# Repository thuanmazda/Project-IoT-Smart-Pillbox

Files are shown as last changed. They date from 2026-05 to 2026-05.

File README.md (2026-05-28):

# 💊 IoT Smart Pillbox - Hộp Thuốc Thông Minh





**IoT Smart Pillbox** là hệ thống hộp thuốc điện tử thông minh được thiết kế nhằm hỗ trợ người cao tuổi và bệnh nhân trong việc tuân thủ phác đồ điều trị. Dự án ứng dụng vi điều khiển ESP32, kết hợp đồng bộ hóa đám mây qua Google Apps Script và hệ thống cảnh báo tức thời qua Telegram.

> **Đồ án môn học 1 (EE3183)** > Khoa Điện - Điện tử, Trường Đại học Bách Khoa - ĐHQG TP.HCM.

---

## ✨ Tính năng nổi bật
* **Định thời gian thực chuẩn xác:** Sử dụng module RTC DS3231 đảm bảo báo thức hoạt động chính xác ngay cả khi mất kết nối Internet.
* **Cấu hình Wi-Fi động (Captive Portal):** Cho phép người dùng kết nối mạng mới thông qua điện thoại thông minh (WiFiManager) mà không cần nạp lại mã nguồn.
* **Theo dõi & Báo cáo đám mây:** Tự động đẩy lịch sử đóng/mở nắp hộp (thông qua công tắc hành trình) lên Google Sheets.
* **Cảnh báo Telegram tức thời:** Gửi tin nhắn thông báo cho người nhà khi đến giờ uống thuốc, uống thuốc trễ hoặc mở hộp sai giờ.
* **Tối ưu năng lượng:** Tích hợp tính năng Deep Dimming (giảm sáng màn hình OLED) để tiết kiệm pin tối đa.
* **Lưu trữ ngoại tuyến (Offline Mode):** Lưu trữ tạm thời dữ liệu vào bộ nhớ Flash (NVS) khi rớt mạng và tự động đồng bộ lại khi có kết nối.

---

## 📂 Cấu trúc thư mục (Directory Tree)

```text
IoT-Smart-Pillbox/
├── 📁 Firmware/
│   └── 📄 ESP32_Pillbox.ino          # Mã nguồn C++ nạp cho vi điều khiển ESP32 (File đọc Arduino IDE)
│   └── 📄 ESP32_Pillbox.cpp          # Mã nguồn C++ nạp cho vi điều khiển ESP32 (File chuẩn hoá định dạng code C++)
├── 📁 Web_App_Script/
│   ├── 📄 Code.gs                    # Mã nguồn Backend (Google Apps Script)
│   └── 📄 Index.html                 # Giao diện Web quản lý (Frontend)
├── 📁 Hardware/
│   ├── 📄 Schematic_Altium.pdf       # File PDF bản vẽ sơ đồ nguyên lý
│   └── 📄 BOM.xlsx                   # Bảng danh mục vật tư (Bill of Materials)
│   └── 📁 Altium PCB Project         # Thư mục chứa toàn bộ dự án thiết kế PCB bằng Altium
├── 📁 Docs/
│   ├── 📄 BAO_CAO_DO_AN_1.pdf        # File báo cáo chi tiết của đề tài
│   └── 📁 Source_Code_LaTeX          # Source Code LaTeX của bài báo cáo 
└── 📄 README.md                      # Tài liệu hướng dẫn của đề tài

```
## 🛠️ Cài đặt & Triển khai hệ thống

### 1. Thi công phần cứng
* Lắp ráp các linh kiện điện tử theo đúng sơ đồ nguyên lý (`Schematic_Altium.pdf`) được cung cấp trong thư mục `Hardware`.
* Dưới đây là hình ảnh nguyên mẫu phần cứng sau khi thi công và tích hợp vào vỏ hộp:

> **📸 Hình ảnh mạch thực tế:**
> 
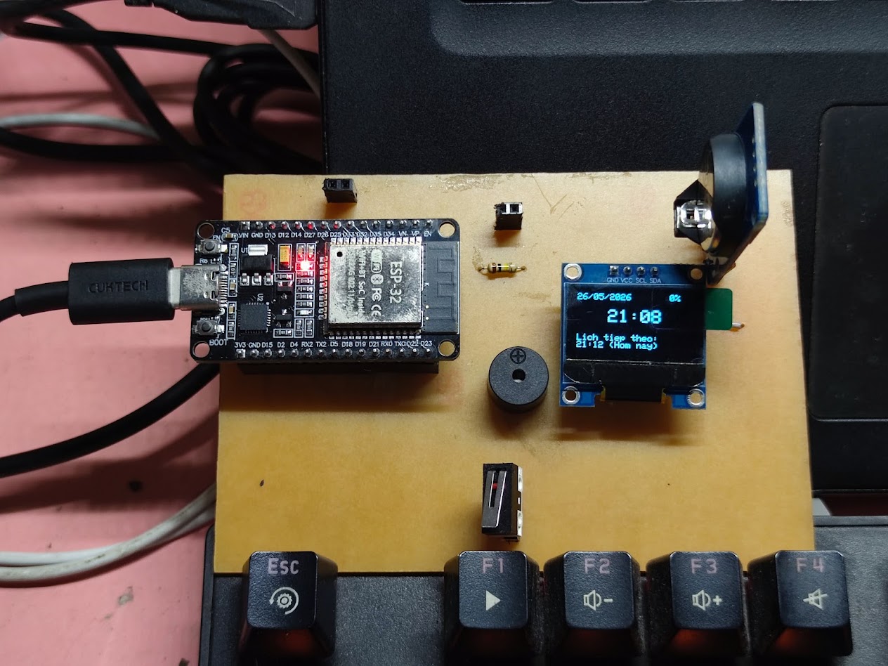
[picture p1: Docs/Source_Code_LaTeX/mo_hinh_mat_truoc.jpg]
Mô hình hoàn thiện
> 

---

### 2. Triển khai Cơ sở dữ liệu (Google Sheets & Apps Script)
Hệ thống sử dụng Google Sheets làm cơ sở dữ liệu miễn phí và Google Apps Script làm Backend API.

1. **Tạo Google Sheet:** Tạo một bảng tính mới để lưu trữ nhật ký.
   * 👉 [🔗 Cơ sở dữ liệu Google Sheet của dự án](https://docs.google.com/spreadsheets/d/1F7vB3ncXRynr4YONkt-7NzRndev7CFtMYesXiH4w0Is/edit?usp=sharingx)
2. **Triển khai Script:** * Mở `Tiện ích mở rộng` -> `Apps Script`.
   * Copy nội dung file `Web_App_Script/Code.gs` và `Index.html` dán vào.
   * Chọn `Phát triển` -> `Triển khai mới` -> Chọn loại `Ứng dụng Web` (Quyền truy cập: Bất kỳ ai).
   * **Lưu lại đường dẫn Web App URL** để nạp vào ESP32.
   * 👉 [🔗 Đường link Web Dashboard của dự án](https://script.google.com/macros/s/AKfycbyWvpzWuLJ_vV84Uc3rvG5cOGRKCblE85hYOkTFurOL_UT4WP3MSYsnFkm6WfHzJIYH/exec)

---

### 3. Nạp mã nguồn ESP32 (Firmware)
1. Cài đặt [Arduino IDE](https://www.arduino.cc/en/software) và thêm board ESP32 vào Board Manager.
2. Cài đặt các thư viện bắt buộc thông qua Library Manager:
   * `WiFiManager` (bởi tzapu)
   * `RTClib` (bởi Adafruit)
   * `Adafruit SSD1306` & `Adafruit GFX Library`
   * `NTPClient` (bởi Fabrice Weinberg)
3. Mở file `Firmware/ESP32_Pillbox.ino`.
4. Tìm đến vùng cấu hình và thay thế các thông số sau bằng thông tin của bạn:
   ```cpp
   String googleScriptUrl = "Dán_Web_App_URL_của_bạn_vào_đây";
   String botToken = "Dán_Token_Telegram_Bot_của_bạn_vào_đây";
   String chatId = "Dán_Chat_ID_của_bạn_vào_đây";
   ```
5. Kết nối ESP32 với máy tính qua cáp Type-C và bấm Upload.

## 🚀 Hướng dẫn Sử dụng Hệ thống

Bước 1: Cấu hình mạng Wi-Fi (Captive Portal)
   * Cấp nguồn cho thiết bị. Nếu mạch chưa có thông tin Wi-Fi, nó sẽ tự động phát ra một mạng Wi-Fi có tên là `Hop_thuoc_IoT`.
   * Dùng điện thoại kết nối vào mạng Wi-Fi này. Một trang đăng nhập sẽ tự động hiện ra (Captive Portal). Bạn chỉ cần chọn mạng Wi-Fi nhà mình, nhập mật khẩu và bấm Save. Thiết bị sẽ tự khởi động lại và online.

Bước 2: Cài đặt lịch trình qua Web Dashboard
  * Truy cập vào đường dẫn Web App (từ bước triển khai Apps Script) bằng điện thoại hoặc máy tính.
  * Tại đây, người quản lý có thể cập nhật các cữ thuốc, xem lịch sử đóng/mở nắp và kiểm tra thống kê tuân thủ.

> **📸 Giao diện Trang quản trị Web:**
> 
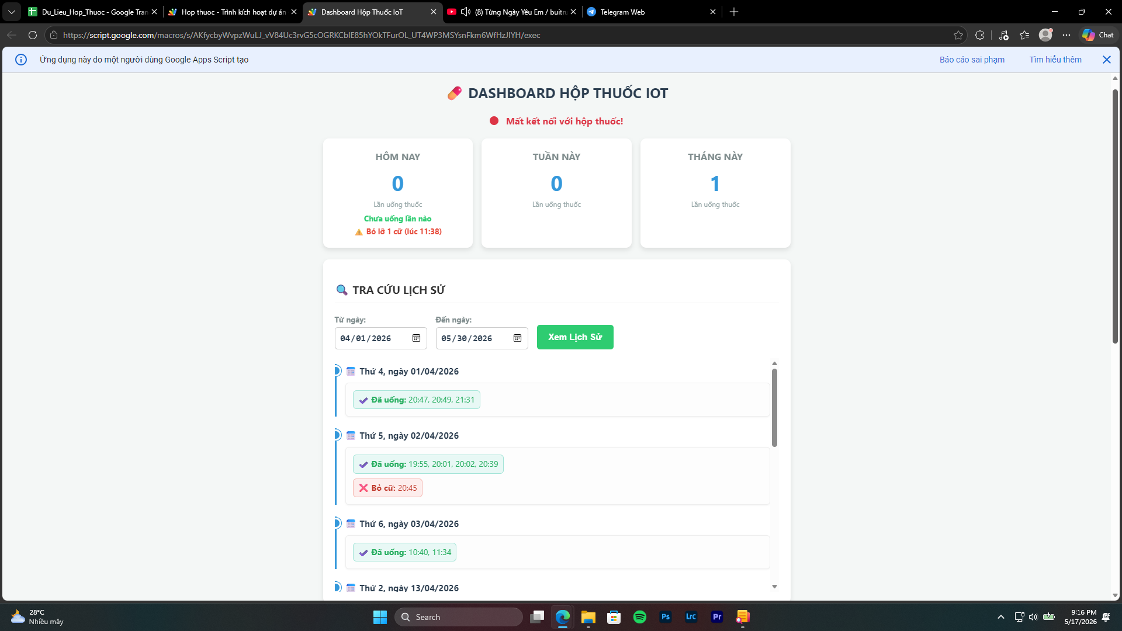
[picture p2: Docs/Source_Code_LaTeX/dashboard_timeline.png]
Giao diện trang web
> 

Bước 3: Nhận thông báo qua Telegram
  * Khi đến giờ, hộp thuốc sẽ phát tiếng bíp và sáng màn hình.
  * Khi người bệnh mở nắp đúng giờ hoặc sai giờ, tin nhắn cảnh báo sẽ ngay lập tức được đẩy về ứng dụng Telegram của người nhà.

> **📸 Thông báo Telegram Bot:**
> 
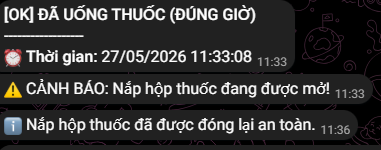
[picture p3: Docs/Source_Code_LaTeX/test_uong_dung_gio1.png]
Thông báo Telegram
> 

---

## 📄 Bản quyền và Cấp phép (Credits & License)

Dự án này là sản phẩm thuộc **Đồ án môn học 1 (EE3183)**. 
Bản quyền mã nguồn, tài liệu và thiết kế cơ khí thuộc về chủ sở hữu (**Nguyễn Minh Thuận**) và **Khoa Điện - Điện tử, Trường Đại học Bách Khoa - ĐHQG TP.HCM**. 

*Vui lòng trích dẫn nguồn đầy đủ và tôn trọng quyền tác giả nếu bạn tham khảo hoặc sử dụng lại các tài liệu từ kho lưu trữ này cho mục đích học tập.*

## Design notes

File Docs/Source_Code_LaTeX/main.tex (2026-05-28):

\documentclass[12pt, a4paper, oneside]{article}
\usepackage[utf8]{vietnam}
\usepackage[utf8]{inputenc}
\usepackage[left=40mm, right=25mm, top=40mm, bottom=25mm]{geometry}
\usepackage{amsmath,amsfonts,amssymb}
\usepackage{indentfirst,enumitem}
\usepackage{graphicx}
\usepackage{multicol}
\usepackage{multirow}
\usepackage{setspace}
\usepackage{hyperref}
\usepackage{listings}
\usepackage{tabularx}
\usepackage{hyperref}
\usepackage{xcolor}
\usepackage{scrextend}
\usepackage{comment}
\usepackage{soul}
\usepackage{tipa}
\usepackage{subcaption}
\usepackage{caption}
\usepackage{booktabs}
\usepackage{array}
\usepackage{fancyhdr}
\usepackage{algorithm2e}
\usepackage{float}
\usepackage[most]{tcolorbox}
\usepackage{pdfpages}
\usepackage{import}
\usepackage{fancyhdr}
\usepackage[T5]{fontenc} % Hỗ trợ tiếng Việt
\usepackage{mathptmx} % Gói Times Roman
\graphicspath{ {figures/} }
\usepackage{titlesec}
\usepackage{tikz}
\usetikzlibrary{shapes.geometric, arrows, positioning, calc}
% Cấu hình Tiêu đề Chương (Section): Canh giữa, in hoa, đậm, cỡ 14
\titleformat{\section}[block]
  {\centering\normalfont\fontsize{14pt}{16.8pt}\bfseries\MakeUppercase}
  {\thesection}
  {0.5em}
  {}
% Cấu hình Tiêu đề Mục (Subsection): Đậm, chữ thường
\titleformat{\subsection}[hang]
  {\normalfont\normalsize\bfseries}
  {\thesubsection}
  {0.5em}
  {}

\captionsetup[table]{position=top, labelfont=bf, textfont=it, font=small, skip=5pt}
\captionsetup[figure]{position=bottom, labelfont=bf, textfont=it, font=small, skip=5pt}

\hypersetup{
    colorlinks=true,
    linkcolor=black,
    filecolor=magenta,      
    urlcolor=black,
    pdftitle={TKHTN},
    pdfpagemode=FullScreen,
}

\changefontsizes{13pt}
\renewcommand\thesection{\arabic{section}.}
\renewcommand\thesubsection{\arabic{section}.\arabic{subsection}}
\setlength{\parindent}{1.25cm}

\pagestyle{fancy}
\renewcommand{\headrulewidth}{0pt}
\fancyhf{} % Xóa cấu hình mặc định
\cfoot{\thepage} % Số trang ở giữa dưới (thường dùng)

\def\mathrlap{\mathpalette\mathrlapinternal} 
\def\mathclap{\mathpalette\mathclapinternal}
\def\mathllapinternal#1#2{\llap{$\mathsurround=0pt#1{#2}$}}
\def\mathrlapinternal#1#2{\rlap{$\mathsurround=0pt#1{#2}$}}

%CHÈN ẢNH
\usepackage{pgfplots}
\pgfplotsset{compat=1.15}
\usepackage{mathrsfs}
\usetikzlibrary{arrows}
\usetikzlibrary[patterns]

%New colors defined below
\definecolor{codegreen}{rgb}{0,0.6,0}
\definecolor{codegray}{rgb}{0.5,0.5,0.5}
\definecolor{codepurple}{rgb}{0.58,0,0.82}
\definecolor{backcolour}{rgb}{0.95,0.95,0.92}

%Code listing style named "mystyle"
\lstdefinestyle{mystyle}{
  backgroundcolor=\color{backcolour},   commentstyle=\color{codegreen},
  keywordstyle=\color{blue},
  numberstyle=\tiny\color{codegray},
  stringstyle=\color{codepurple},
  basicstyle=\ttfamily\footnotesize,
  breakatwhitespace=false,         
  breaklines=true,                 
  captionpos=b,                    
  keepspaces=true,                 
  numbers=left,                    
  numbersep=5pt,                  
  showspaces=false,                
  showstringspaces=false,
  showtabs=false,                  
  tabsize=2
}

%"mystyle" code listing set
\lstset{style=mystyle}

\begin{document}
\begin{titlepage}
%\SetWatermarkText{\includegraphics[width = 0.97\paperwidth,
%height = 0.97\paperheight]{bia.png}}
%\SetWatermarkAngle{0} 
%\SetWatermarkText{\includegraphics[scale=1]{hust.png}}
%\SetWatermarkAngle{0} 
\begin{tikzpicture}[remember picture,overlay,inner sep=0,outer sep=0]
     % Đã đổi xshift ở B và C từ 1.5cm thành 3cm để dịch khung sang phải né gáy sách 40mm
     \draw[blue!70!black,line width=4pt] ([xshift=-1.5cm,yshift=-2cm]current page.north east) coordinate (A)--([xshift=3cm,yshift=-2cm]current page.north west) coordinate(B)--([xshift=3cm,yshift=2cm]current page.south west) coordinate (C)--([xshift=-1.5cm,yshift=2cm]current page.south east) coordinate(D)--cycle;

     \draw ([yshift=0.5cm,xshift=-0.5cm]A)-- ([yshift=0.5cm,xshift=0.5cm]B)--
     ([yshift=-0.5cm,xshift=0.5cm]B) --([yshift=-0.5cm,xshift=-0.5cm]B)--([yshift=0.5cm,xshift=-0.5cm]C)--([yshift=0.5cm,xshift=0.5cm]C)--([yshift=-0.5cm,xshift=0.5cm]C)-- ([yshift=-0.5cm,xshift=-0.5cm]D)--([yshift=0.5cm,xshift=-0.5cm]D)--([yshift=0.5cm,xshift=0.5cm]D)--([yshift=-0.5cm,xshift=0.5cm]A)--([yshift=-0.5cm,xshift=-0.5cm]A)--([yshift=0.5cm,xshift=-0.5cm]A);

     \draw ([yshift=-0.3cm,xshift=0.3cm]A)-- ([yshift=-0.3cm,xshift=-0.3cm]B)--
     ([yshift=0.3cm,xshift=-0.3cm]B) --([yshift=0.3cm,xshift=0.3cm]B)--([yshift=-0.3cm,xshift=0.3cm]C)--([yshift=-0.3cm,xshift=-0.3cm]C)--([yshift=0.3cm,xshift=-0.3cm]C)-- ([yshift=0.3cm,xshift=0.3cm]D)--([yshift=-0.3cm,xshift=0.3cm]D)--([yshift=-0.3cm,xshift=-0.3cm]D)--([yshift=0.3cm,xshift=-0.3cm]A)--([yshift=0.3cm,xshift=0.3cm]A)--([yshift=-0.3cm,xshift=0.3cm]A);
\end{tikzpicture}
\begin{center}
    \vspace{7pt}
        \textbf{ĐẠI HỌC QUỐC GIA THÀNH PHỐ HỒ CHÍ MINH}
    
    \vspace{7pt}
    {TRƯỜNG ĐẠI HỌC BÁCH KHOA}
    
    \vspace{7pt}
    {KHOA ĐIỆN - ĐIỆN TỬ}

\end{center}
\vspace{10pt}
\begin{center}
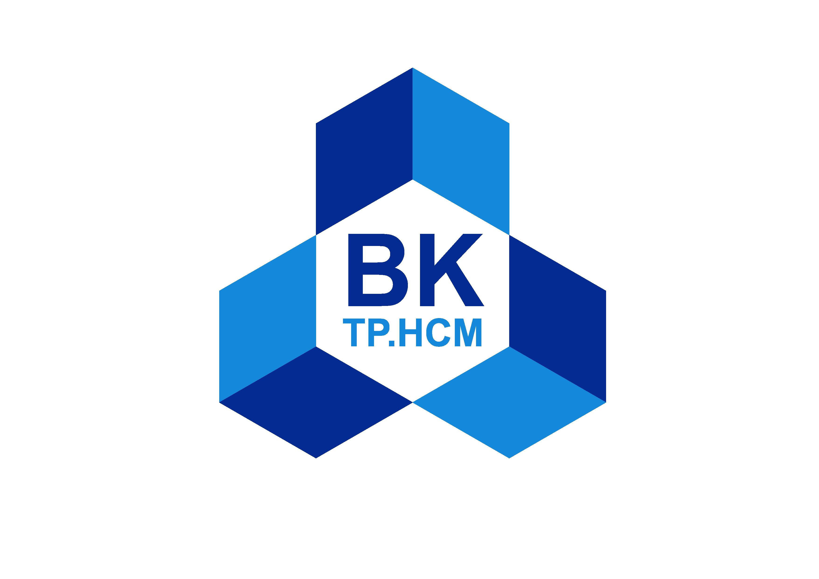
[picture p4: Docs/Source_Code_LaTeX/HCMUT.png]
    
    
    \vspace{10pt}
\end{center}

\begin{center}
    \fontsize{18pt}{17pt}\selectfont 
    \textbf{ĐỒ ÁN MÔN HỌC 1 (EE3183)}
\end{center}
\begin{center}
    \fontsize{15pt}{17pt}\selectfont 
    \textbf{\textrm{ĐỀ TÀI: THIẾT KẾ HỘP THUỐC THÔNG MINH IOT - 
    \\
    IOT SMART PILLBOX}}
\end{center}

\begin{center}
    \vspace{15pt}
% \textbf{Lớp: L03 - NHÓM: 5}
\end{center}

\vspace{10pt}

\begin{table}[h]
\begin{tabular}{rrl}
\hspace{6 cm} & SVTH: &Nguyễn Minh Thuận\\
& MSSV: &2313355\\
& GVHD: &TS. Nguyễn Thanh Tuấn
\end{tabular}
\end{table}
\vfill
\centerline{\bf Thành phố Hồ Chí Minh, tháng 6 năm 2026}

\vspace{1cm}
\end{titlepage}

\newpage

\newpage
\thispagestyle{empty}
\setstretch{1.3}
\begin{center}
    \textbf{LỜI CẢM ƠN}
\end{center}

\textit{Em xin gửi lời cảm ơn chân thành và sự tri ân sâu sắc đối với thầy Nguyễn Thanh Tuấn, giảng viên Bộ môn Viễn Thông, Khoa Điện - Điện tử, Trường Đại học Bách khoa - Đại học Quốc gia Thành phố Hồ Chí Minh, đã tạo điều kiện cho em có thể hoàn thành được học phần Đồ Án 1 này. Và em cũng xin chân thành cảm ơn thầy đã nhiệt tình hướng dẫn, chỉ ra những điều còn thiếu sót trong qua trình thực hiện đề tài để có được kết quả tốt đẹp như mong muốn và hoàn thành tốt học phần này.}

\textit{Trong quá trình thực hiện đề tài, thầy đã chỉ dẫn, góp ý và giúp em khắc phục những thiếu sót để đạt được kết quả tốt hơn. Do hạn chế về kiến thức và kinh nghiệm thực tiễn, bài báo cáo không thể tránh khỏi những sai sót. Em rất mong nhận được sự thông cảm và những ý kiến đóng góp quý báu từ thầy để có thể hoàn thiện hơn trong các học phần tiếp theo cũng như trong đồ án và luận văn tốt nghiệp sau này.}

\textit{Em xin chân thành cảm ơn Thầy!}

\textit{Chúc Thầy sức khỏe và thành đạt.}

\vspace{4cm}

\hspace{5cm}\textit{Tp. Hồ Chí Minh, ngày .... tháng .... năm ........}

\hspace{8cm}\textbf{Sinh viên}

\newpage
\thispagestyle{empty}
\setstretch{1.3}
\begin{center}
    \textbf{TÓM TẮT ĐỀ TÀI}
\end{center}

Tuân thủ phác đồ điều trị và uống thuốc đúng giờ là yếu tố tiên quyết quyết định hiệu quả của quá trình chăm sóc y tế, đặc biệt đối với người cao tuổi và bệnh nhân mắc các bệnh mãn tính. Tuy nhiên, tình trạng quên uống thuốc, uống sai cữ hoặc bỏ liều vẫn thường xuyên diễn ra do sự suy giảm trí nhớ hoặc nhịp sống bận rộn. Nhằm giải quyết triệt để vấn đề này, đề tài "Thiết kế hộp thuốc thông minh IoT - IoT Smart Pillbox" được triển khai với mục tiêu xây dựng một hệ sinh thái hỗ trợ quản lý y tế cá nhân khép kín, tự động và theo thời gian thực. 

Cốt lõi của hệ thống được phát triển dựa trên vi điều khiển trung tâm ESP32, kết hợp cùng công tắc hành trình để giám sát chính xác các thao tác vật lý, màn hình OLED 0.96 inch để giao tiếp trực quan và còi báo chủ động nhằm tạo ra chu trình nhắc nhở hiệu quả. Thiết bị đảm bảo tính di động và vận hành liên tục nhờ cơ chế cấp nguồn linh hoạt qua cổng USB Type-C hoặc hệ thống pin Lithium-ion đi kèm mạch quản lý năng lượng. 

Điểm đột phá của đề tài nằm ở việc ứng dụng kiến trúc điện toán phi máy chủ (Serverless) thay cho các máy chủ trung gian truyền thống, sử dụng Google Apps Script làm nền tảng Backend và Google Sheets làm cơ sở dữ liệu. Nhờ triển khai các thuật toán xử lý đa nhiệm không đồng bộ (non-blocking) trên vi điều khiển, thiết bị có khả năng đánh giá và phân loại chính xác các trạng thái phức tạp như "Đã uống", "Bỏ thuốc" hay "Uống trễ". Toàn bộ dữ liệu được đồng bộ hóa với một trang quản trị trực tuyến (Web Dashboard), cho phép người nhà hoặc bác sĩ dễ dàng thiết lập lịch trình từ xa, tra cứu nhật ký y tế và nhận thông báo cảnh báo tức thời qua ứng dụng Telegram. 

Kết quả thực nghiệm khẳng định hệ thống vận hành ổn định, độ trễ truyền tải thấp và logic xử lý đáp ứng trọn vẹn các kịch bản thực tế, qua đó mở ra tiềm năng ứng dụng mạnh mẽ cho các thiết bị y tế thông minh phân tán trong tương lai.

\newpage
\thispagestyle{empty}
\setstretch{1.3}
\renewcommand{\contentsname}{\centering {MỤC LỤC}}
\tableofcontents

\newpage
\setcounter{page}{1}

\begin{center}
    \section{GIỚI THIỆU}
\end{center}
\subsection{Tổng quan}
%Nội dung 1.1
Sự phát triển bùng nổ của Internet vạn vật (IoT) đã và đang tạo ra những bước nhảy vọt trong lĩnh vực y tế số (Digital Health). Xu hướng chuyển dịch từ việc chăm sóc sức khỏe tập trung tại bệnh viện sang giám sát cá nhân hóa tại gia đình đang ngày càng trở nên phổ biến. Trong bối cảnh đó, vấn đề tuân thủ thời gian biểu sử dụng thuốc (Medication Adherence) nổi lên như một thách thức lớn. Theo nhiều báo cáo y khoa, việc người bệnh (đặc biệt là người cao tuổi, người suy giảm trí nhớ) quên uống thuốc, uống quá liều hoặc sai cữ không chỉ làm vô hiệu hóa phác đồ điều trị mà còn gây ra những biến chứng nguy hiểm, gia tăng gánh nặng cho hệ thống y tế.

Xuất phát từ nhu cầu thực tiễn cấp thiết đó, đề tài "Thiết kế hộp thuốc thông minh IoT" được đề xuất và thực hiện. Không chỉ dừng lại ở một thiết bị phần cứng phát tiếng kêu báo thức đơn thuần, đề tài hướng tới việc xây dựng một hệ thống quản lý dữ liệu y tế toàn diện. Sự kết hợp giữa vi điều khiển có kết nối Wi-Fi (ESP32) tại nơi người bệnh và sức mạnh xử lý của điện toán đám mây (Cloud Computing) tạo ra một luồng thông tin xuyên suốt. Người nhà hoặc bác sĩ có thể dễ dàng thiết lập phác đồ uống thuốc từ xa, trong khi hệ thống phần cứng sẽ tự động tương tác với bệnh nhân và gửi báo cáo hành vi chi tiết (đúng giờ, trễ giờ, bỏ cữ) theo thời gian thực về máy chủ.

\subsection{Tình hình nghiên cứu trong và ngoài nước}
%Nội dung 1.2
\subsubsection{Tình hình nghiên cứu ngoài nước:} 

Trên thị trường quốc tế, các sản phẩm hộp thuốc thông minh đã bắt đầu được thương mại hóa, tiêu biểu như các dòng sản phẩm của Ellie, Medisafe hay Hero. Các hệ thống này thường có thiết kế cơ khí tinh xảo, phân chia nhiều ngăn tự động. Về mặt công nghệ, chúng chủ yếu sử dụng giao thức Bluetooth (BLE) để đồng bộ dữ liệu với ứng dụng trên điện thoại thông minh (Smartphone) của người dùng, hoặc sử dụng Wi-Fi để kết nối với các máy chủ đám mây độc quyền (Proprietary Cloud). Nhược điểm chung của các giải pháp này là giá thành phần cứng rất cao, bắt buộc người dùng phải trả phí thuê bao (Subscription) hàng tháng để duy trì dịch vụ lưu trữ dữ liệu, và quá trình thiết lập ứng dụng đi kèm khá phức tạp đối với tệp người dùng là người cao tuổi.

\subsubsection{Tình hình nghiên cứu trong nước:} 

Tại Việt Nam, các nghiên cứu và sản phẩm ứng dụng IoT trong quản lý hộp thuốc chủ yếu xuất hiện dưới dạng các mô hình đồ án sinh viên hoặc sản phẩm khởi nghiệp quy mô nhỏ. Đa số các mô hình sử dụng vi điều khiển như Arduino Uno kết hợp module ESP8266, hoặc sử dụng cơ sở dữ liệu thời gian thực Firebase của Google. Dù giải quyết được bài toán chi phí, nhưng các mô hình này thường thiếu tính đồng bộ và độ tin cậy. Các hệ thống đa phần gặp giới hạn ở việc xử lý đa nhiệm (bị treo hệ thống khi chờ kết nối mạng), không có giao diện Web tổng quan (Dashboard) độc lập mà phụ thuộc vào các nền tảng có sẵn như Blynk, và chưa tối ưu hóa được thuật toán phân tích hành vi "uống trễ" của người bệnh.

Đề tài này được thực hiện nhằm khắc phục các nhược điểm trên, bằng cách tự chủ hoàn toàn giao diện Web, tận dụng kiến trúc API của Google Apps Script để miễn phí hóa khâu lưu trữ, và xây dựng một nền tảng phần mềm nhúng hoạt động ổn định không bị tắc nghẽn.

\subsection{Nhiệm vụ đề tài}
%Nội dung 1.3
Để đạt được các mục tiêu đã đề ra, đề tài tập trung giải quyết các nhiệm vụ trọng tâm sau:
\begin{itemize}
    \item \textbf{Thiết kế và thi công phần cứng:} Lựa chọn linh kiện và thiết kế sơ đồ mạch điện xung quanh vi điều khiển trung tâm ESP32. Tích hợp màn hình OLED I2C, còi báo động, công tắc hành trình dạng đòn bẩy nảy (Limit switch).
    \item \textbf{Phát triển phần mềm nhúng:} Lập trình ESP32 trên nền tảng C++ với thuật toán xử lý đa nhiệm theo thời gian thực sử dụng hàm \texttt{millis()}, loại bỏ hoàn toàn các hàm dừng (delay) gây treo hệ thống. Triển khai giao thức NTP để đồng bộ thời gian chuẩn xác và HTTPS để truyền/nhận dữ liệu bảo mật.
    \item \textbf{Thiết kế hệ thống Điện toán đám mây:} Xây dựng mã nguồn Google Apps Script (GAS) đóng vai trò làm máy chủ API, xử lý các yêu cầu GET/POST từ mạch ESP32 và định tuyến dữ liệu vào bảng tính Google Sheets để lưu trữ dài hạn.
    \item \textbf{Phát triển Giao diện Người dùng (UI/UX):} Thiết kế và lập trình một trang Web Dashboard (sử dụng HTML/CSS/JavaScript) cho phép thiết lập lịch báo thức đa dạng (theo thứ trong tuần) và hiển thị thống kê lịch sử trực quan. Tích hợp API của Telegram để khởi tạo Bot thông báo từ xa.
    \item \textbf{Thử nghiệm và đánh giá:} Cấu hình cơ chế khôi phục mạng nội bộ và tiến hành đánh giá độ ổn định của toàn bộ hệ thống dưới các điều kiện vận hành thực tế.
\end{itemize}

\newpage
\begin{center}
    \section{LÝ THUYẾT}
\end{center}
%Nội dung chương 2
\subsection{Vi điều khiển trung tâm ESP32 NodeMCU Devkit V1}
\subsubsection{Kiến trúc phần cứng vi xử lý}

ESP32 NodeMCU Devkit V1 là bo mạch phát triển mã nguồn mở, được thiết kế tích hợp module hệ thống trên chip (SoC) ESP32-WROOM-32 do hãng Espressif Systems sản xuất.

Trái tim của hệ thống là bộ vi xử lý Xtensa® Dual-Core 32-bit LX6. Khác với các dòng vi điều khiển lõi đơn truyền thống như ATmega328P, kiến trúc lõi kép của ESP32 mang lại khả năng xử lý bất đối xứng trên nền tảng hệ điều hành thời gian thực FreeRTOS.

\begin{itemize}
    \item \textit{ Lõi PRO\_CPU}: Chuyên trách xử lý các luồng tác vụ ngầm ở tầng thấp như ngăn xếp giao thức Wi-Fi, Bluetooth và quản lý các ngắt phần cứng cường độ cao.
    \item \textit{Lõi APP\_CPU}: Được giải phóng hoàn toàn để thực thi mã chương trình của người dùng (logic giám sát hành trình nắp hộp, xuất tín hiệu âm thanh và cập nhật màn hình OLED). 
    Hệ thống sử dụng đường dẫn dữ liệu (Data bus) và đường dẫn lệnh (Instruction bus) độc lập theo kiến trúc Harvard, mang lại khả năng tính toán lên đến 600 DMIPS, đáp ứng hoàn hảo yêu cầu phân tích (parsing) các chuỗi dữ liệu JSON phức tạp tải về từ máy chủ đám mây.
\end{itemize}

\begin{figure}
    \centering
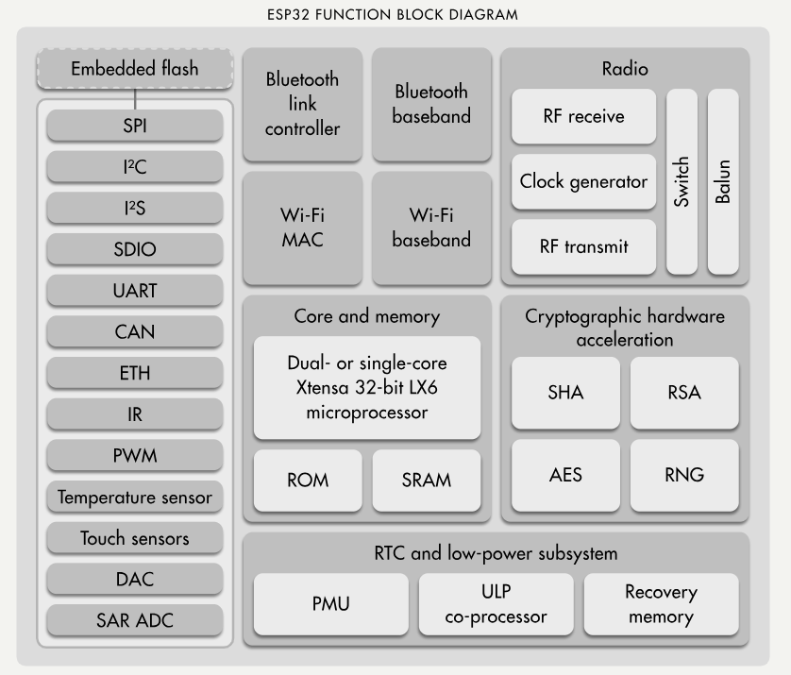
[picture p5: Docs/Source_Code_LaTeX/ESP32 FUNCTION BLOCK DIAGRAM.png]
    
    \caption{Sơ đồ khối chức năng của ESP32}
    \label{fig:espblockdiagram}
\end{figure}

\newpage
\subsubsection{Thông số kỹ thuật chi tiết và Ngoại vi}

Dựa trên tài liệu kỹ thuật của nhà sản xuất, SoC ESP32-WROOM-32 sở hữu các thông số phần cứng vượt trội, đáp ứng tiêu chuẩn của một thiết bị IoT công nghiệp:

\begin{itemize}
    \item Hệ thống Nguồn điện: Điện áp hoạt động lõi của chip là $2.2V - 3.6V$. Tuy nhiên, trên mạch Devkit V1 đã được tích hợp sẵn IC ổn áp tuyến tính như AMS1117-3.3, cho phép cấp nguồn $5V$ an toàn qua cổng Micro-USB hoặc chân VIN. Chip được trang bị bộ xử lý đồng xử lý siêu tiết kiệm năng lượng (ULP), cho phép dòng tiêu thụ giảm xuống mức cực thấp (khoảng $10 \mu A$) ở chế độ Ngủ sâu (Deep-sleep), rất lý tưởng cho các thiết bị y tế chạy pin.
    \item Hệ thống Bộ nhớ: Tích hợp sẵn $520 KB$ SRAM nội bộ và $448 KB$ ROM. Ngoài ra, module WROOM-32 được gắn kèm một chip nhớ Flash SPI ngoại vi dung lượng $4MB$ (hoặc $8MB$ tùy phiên bản), cung cấp không gian rộng rãi để lưu trữ Firmware, hệ thống tệp tĩnh (SPIFFS) và cơ sở dữ liệu nội bộ.
    \item Giao tiếp Ngoại vi (I/O Interfaces): Mạch cung cấp tổng cộng 34 chân GPIO với khả năng ghép kênh linh hoạt bằng phần mềm.
    \begin{itemize}
        \item Giao tiếp số: Hỗ trợ phần cứng chuyên dụng cho 3 x UART, 3 x SPI, 2 x I2C và 2 x I2S
        \item Giao tiếp tương tự: Tích hợp bộ chuyển đổi tương tự - số (ADC) kiến trúc SAR 12-bit với 18 kênh; và bộ chuyển đổi số - tương tự (DAC) 8-bit với 2 kênh.
        \item Cảm biến tích hợp: Chip tích hợp sẵn cảm biến hiệu ứng Hall (đo từ trường) và 10 chân GPIO hỗ trợ cảm biến điện dung, cho phép thiết kế các nút bấm không tiếp xúc cơ học.
    \end{itemize}
\end{itemize}
\subsubsection{Khả năng vô tuyến: Wi-Fi và Bluetooth}
Khả năng tích hợp RF trên ESP32 là một bước tiến lớn trong thiết kế bán dẫn, bao gồm bộ thu phát vô tuyến, bộ khuếch đại nhiễu thấp (LNA), bộ khuếch đại công suất (PA) và bộ chuyển mạch ăng-ten (Antenna switch) được nhúng gọn trong cùng một đế silicon (kích thước chỉ $18mm \times 25.5mm$).

\begin{itemize}
    \item Tầng Vật lý Wi-Fi: Tuân thủ chuẩn IEEE 802.11 b/g/n, hoạt động ở băng tần $2.4 GHz$ ISM. ESP32 hỗ trợ cấu trúc liên kết mạng linh hoạt: chế độ Station (thiết bị đầu cuối kết nối vào Router), SoftAP (tự phát mạng nội bộ) và kết hợp BSS. Với công suất phát định mức lên đến $+19.5 dBm$ (chuẩn 802.11b) và độ nhạy thu (RX Sensitivity) đạt $-97 dBm$, thiết bị đảm bảo duy trì liên kết vô tuyến ổn định, khắc phục hiện tượng suy hao tín hiệu khi hộp thuốc đặt trong phòng kín hoặc vùng có vật cản.
    \item Kết nối Bluetooth: Tích hợp bộ điều khiển băng tần cơ sở hỗ trợ chuẩn Bluetooth v4.2 BR/EDR và đặc biệt là Bluetooth Low Energy (BLE). Trong kiến trúc IoT hiện đại, BLE mở ra hướng phát triển cho việc cấu hình mạng cục bộ hoặc giao tiếp trực tiếp với các thiết bị đeo tay thông minh của người bệnh để đồng bộ nhịp tim và nhắc nhở uống thuốc mà không cần thông qua Internet.
\end{itemize}
\subsection{Nền tảng Giao thức Mạng và Đồng bộ hệ thống}

Để hiện thực hóa kiến trúc Internet vạn vật (IoT), hệ thống không giới hạn ở tầng vật lý mà đòi hỏi việc thực thi các ngăn xếp giao thức (Protocol Stack) chuẩn mực trên nền tảng TCP/IP, đảm bảo tính bảo mật và độ chính xác thời gian tuyệt đối.

\subsubsection{Giao thức HTTPS (Hypertext Transfer Protocol Secure)}

Trong đề tài này, ESP32 tương tác trực tiếp với hệ sinh thái máy chủ đám mây của Google (Google Apps Script) mà không qua bất kỳ Broker trung gian nào. Do tính chất dữ liệu y tế cần độ bảo mật cao, giao thức HTTPS được áp dụng tại tầng Ứng dụng (Application Layer).

HTTPS là phần mở rộng bảo mật của giao thức HTTP, hoạt động qua cổng 443. Khác với giao thức HTTP truyền văn bản gốc (plaintext) dễ bị tấn công nghe lén (Packet Sniffing), HTTPS thiết lập một đường hầm bảo mật bằng giao thức TLS/SSL (Transport Layer Security).

\begin{itemize}
    \item Quá trình Handshake: ESP32 và máy chủ Google trao đổi thông tin để thống nhất bộ thuật toán mã hóa (Cipher Suite).
    \item Mã hóa phi đối xứng: Sử dụng các thuật toán như RSA hay ECC để trao đổi khóa phiên một cách an toàn.
    \item Mã hóa đối xứng: Sau khi có khóa phiên, toàn bộ dữ liệu tải trọng (Payload) – bao gồm lệnh Mo\_Nap hay chuỗi lịch sử báo thức – đều được mã hóa bằng AES-256.
    
    Đặc tính kỹ thuật trên ESP32: Quá trình xác thực chứng chỉ số tốn rất nhiều tài nguyên RAM. Để tối ưu hóa giới hạn bộ nhớ của vi điều khiển, thư viện \texttt{WiFiClientSecure} được cấu hình ở chế độ \texttt{setInsecure()}. Kỹ thuật này bỏ qua việc kiểm tra tính hợp lệ của chuỗi chứng chỉ máy chủ nhưng vẫn duy trì kênh mã hóa dữ liệu đầu cuối, đảm bảo cân bằng giữa bài toán bảo mật và hiệu năng phần cứng nhúng.
\end{itemize}

\subsubsection{Giao thức đồng bộ thời gian mạng NTP (Network Time Protocol)}

Tính năng cốt lõi của "Hộp thuốc thông minh" là báo thức chính xác. Do ESP32 không được trang bị mạch đồng hồ thời gian thực (RTC) chạy pin CMOS độc lập, việc lấy giờ chuẩn được phó thác hoàn toàn cho giao thức NTP.

NTP hoạt động trên nền tảng giao thức phi kết nối UDP (User Datagram Protocol) tại cổng 123. Nó được thiết kế để đồng bộ hóa đồng hồ của các hệ thống máy tính với các nguồn thời gian chuẩn toàn cầu (Stratum 1, Stratum 2).

Thuật toán cốt lõi của NTP không chỉ đơn thuần là "hỏi giờ". Khi ESP32 gửi gói tin yêu cầu đến máy chủ (ví dụ \texttt{pool.ntp.org}), thuật toán sẽ ghi nhận 4 dấu thời gian (timestamps): thời điểm đi, thời điểm máy chủ nhận, thời điểm máy chủ phản hồi và thời điểm ESP32 nhận lại. Dựa vào 4 biến số này, ngăn xếp giao thức sẽ tính toán được:

\begin{itemize}
    \item Độ trễ đường truyền (Network Delay): Tổng thời gian gói tin di chuyển trên không gian mạng.
    \item Độ lệch đồng hồ (Clock Offset): Sự chênh lệch thời gian thực tế giữa hệ thống dao động thạch anh nội bộ của ESP32 và đồng hồ nguyên tử của máy chủ.
    
Bằng cách bù trừ các sai số này, giao thức NTP cung cấp cho hộp thuốc một mốc thời gian (Epoch time) với sai số chỉ ở mức mili-giây, đảm bảo cữ thuốc được nhắc nhở chính xác theo thời gian thực tại múi giờ địa phương (GMT+7).
\end{itemize}

\subsection{Màn hình OLED 0.96 inch và Giao thức I2C}

\begin{figure}[H]
    \centering
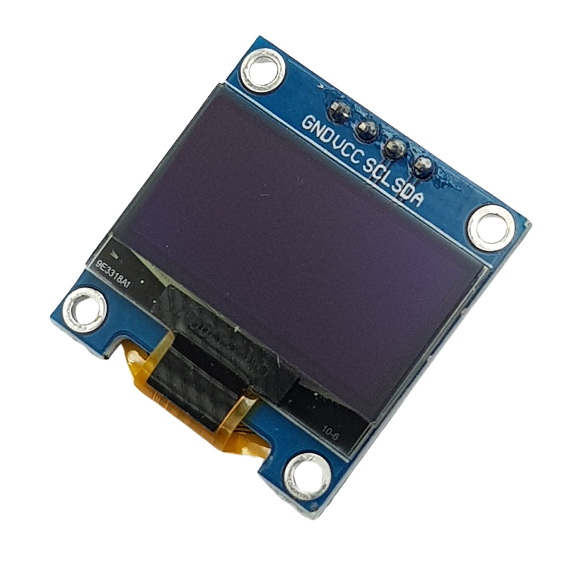
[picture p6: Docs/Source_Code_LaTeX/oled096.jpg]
    
    \caption{Màn hình OLED 0.96 Inch 128x64}
    \label{fig:oled096}
\end{figure}

\subsubsection{Nguyên lý công nghệ hiển thị OLED}

OLED (Organic Light Emitting Diode) là công nghệ đi-ốt phát quang hữu cơ. Khác với màn hình LCD (Liquid Crystal Display) truyền thống sử dụng một tấm đèn nền (Backlight) chiếu sáng liên tục xuyên qua các tinh thể lỏng, màn hình OLED hoạt động dựa trên hiện tượng phát quang điện từ (Electroluminescence) của vật liệu hữu cơ. Khi có một điện áp được đặt giữa cực Anode và Cathode, các lỗ trống và electron sẽ di chuyển và tái hợp tại lớp phát sáng hữu cơ, giải phóng năng lượng dưới dạng photon ánh sáng.

Nhờ khả năng "tự phát sáng" tại từng điểm ảnh (pixel), màn hình OLED có thể tắt hoàn toàn các pixel tại vùng hiển thị màu đen. Điều này tạo ra độ tương phản gần như vô hạn, không có hiện tượng hở sáng (light bleeding) và mức tiêu thụ năng lượng cực thấp (chỉ khoảng 20mA - 30mA khi hiển thị văn bản).

\subsubsection{Giao thức I2C (Inter-Integrated Circuit)}

Để điều khiển 8192 điểm ảnh (128x64 pixel), module sử dụng IC điều khiển SSD1306 tích hợp bộ nhớ GDDRAM (Graphic Display Data RAM) tĩnh dung lượng 1KB. Thay vì sử dụng chuẩn SPI song song tốn nhiều chân GPIO, module OLED này giao tiếp với ESP32 thông qua bus I2C đa chủ - đa tớ (Multi-master, Multi-slave).

I2C hoạt động thông qua hai đường tín hiệu truyền dẫn đồng bộ:

\begin{itemize}
    \item SDA (Serial Data Line): Đường truyền dữ liệu hai chiều dạng nối tiếp.
    \item SCL (Serial Clock Line): Đường xung nhịp đồng bộ, được tạo ra bởi thiết bị Chủ (ESP32).
\end{itemize}

Quá trình giao tiếp bắt đầu khi ESP32 kéo đường SDA xuống mức Thấp (LOW) trong khi SCL đang ở mức Cao (HIGH), tạo ra điều kiện Khởi động (Start Condition). Tiếp theo, ESP32 gửi đi byte Địa chỉ thiết bị (Device Address - của màn hình OLED thường là 0x3C). SSD1306 nhận dạng địa chỉ và trả về một bit xác nhận (ACK). Sau đó, ESP32 tiến hành truyền các luồng dữ liệu (Data frames) chứa mã lệnh cấu hình (Command) hoặc mã ma trận điểm ảnh (Data) vào vùng nhớ GDDRAM, quá trình kết thúc bằng điều kiện Dừng (Stop Condition). Tốc độ truyền tải I2C trong cấu hình mặc định đạt 100 kHz (Standard-mode) hoặc 400 kHz (Fast-mode), hoàn toàn đáp ứng được tốc độ làm tươi màn hình thời gian thực của đồ án.

\subsection{Còi báo hiệu chủ động (Active Buzzer) và Hiệu ứng Áp điện}

\newpage
\begin{figure}
    \centering
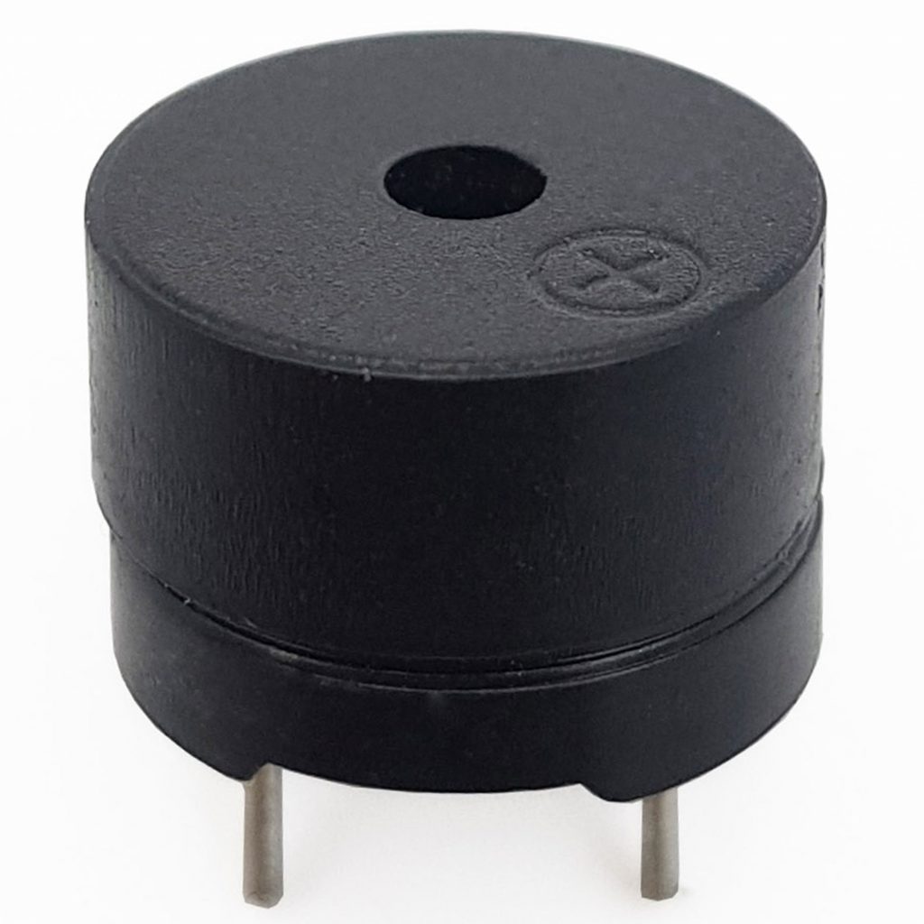
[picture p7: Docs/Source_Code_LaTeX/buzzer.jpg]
    
    \caption{Buzzer Chirp}
    \label{fig:buzzer}
\end{figure}

\newpage
\subsubsection{Cấu trúc và Hiệu ứng Áp điện nghịch}

Buzzer trong đề tài sử dụng bộ chuyển đổi âm thanh dạng áp điện (Piezoelectric transducer). Thành phần cốt lõi của nó là một đĩa gốm áp điện (thường làm từ vật liệu Lead Zirconate Titanate - PZT) được dán chặt vào một tấm màng kim loại mỏng (màng rung).

Nguyên lý hoạt động dựa trên Hiệu ứng áp điện nghịch (Inverse Piezoelectric Effect): Khi đặt một điện trường (bằng cách cấp điện áp) xuyên qua màng gốm PZT, mạng tinh thể của vật liệu sẽ bị biến dạng cơ học (co lại hoặc giãn ra). Khi đặt một dòng điện xoay chiều (AC) vào đĩa gốm, sự biến dạng liên tục và có chu kỳ sẽ khiến tấm màng kim loại uốn cong qua lại, từ đó đẩy lớp không khí xung quanh, tạo ra sóng âm thanh truyền đến tai người.

\subsubsection{Kiến trúc Mạch dao động nội (Active Circuitry)}

Khác biệt hoàn toàn với Passive Buzzer (cần vi điều khiển cấp xung PWM xoay chiều để tạo âm thanh), Active Buzzer được coi là một "linh kiện thông minh" độc lập vì nó tích hợp sẵn một mạch dao động đa hài (Multivibrator Oscillator circuit) ngay trên bo mạch nền của vỏ còi.

Mạch dao động này thường bao gồm các transistor và tụ điện, thiết lập sẵn một dải tần số cộng hưởng cố định (ví dụ: 2500 Hz). Khi vi điều khiển ESP32 xuất một tín hiệu logic mức CAO (3.3V) từ chân GPIO vào chân điều khiển của Buzzer, tín hiệu điện một chiều (DC) này sẽ cung cấp năng lượng cho mạch đa hài. Mạch đa hài tự động băm dòng điện DC thành các xung vuông AC ở tần số 2500 Hz và cấp thẳng vào đĩa áp điện. Nhờ đặc tính này, hệ thống nhúng giảm tải được hoàn toàn việc phải sử dụng các bộ định thời (Timer) phức tạp để tạo xung âm thanh, thay vào đó chỉ cần điều khiển trạng thái BẬT/TẮT ở tầng ứng dụng.

\subsection{Công tắc hành trình (Micro Limit Switch) và Cơ chế Cơ điện}

\begin{figure}[H]
    \centering
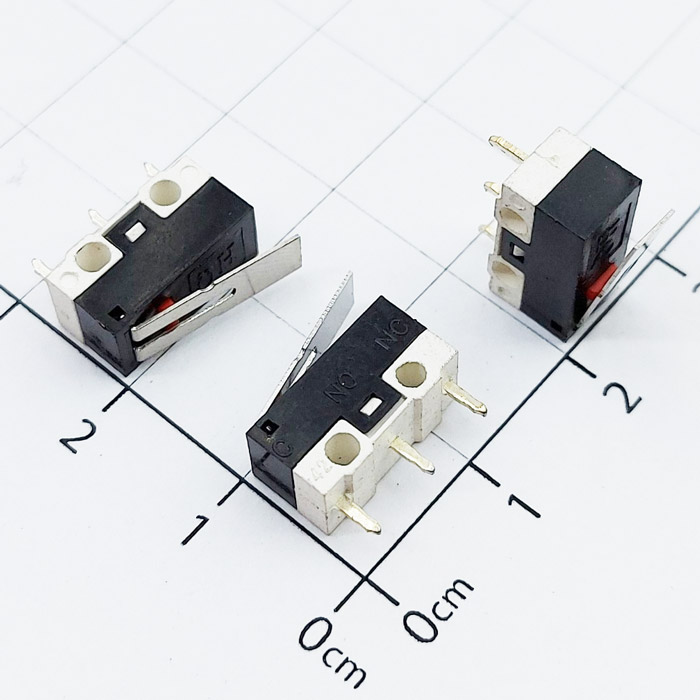
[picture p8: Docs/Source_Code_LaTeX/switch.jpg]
    
    \caption{Công tắc hành trình}
    \label{fig:switch}
\end{figure}

\newpage
\subsubsection{Kiến trúc Đòn bẩy nảy}

Công tắc hành trình (Micro Switch) là một cảm biến tiếp xúc cơ học, đóng vai trò sống còn trong việc phát hiện trạng thái nắp hộp thuốc một cách chính xác tuyệt đối. Khác với các nút nhấn màng carbon tĩnh, Micro Switch hoạt động dựa trên cơ chế vật lý "Snap-action" (Cơ cấu đòn bẩy nảy hoặc Cơ cấu quá tâm - Over-center mechanism).

Bên trong công tắc là một hệ thống đòn bẩy kết hợp với một lò xo lá hợp kim có độ đàn hồi cao (Beryllium Copper). Các tiếp điểm được mạ Bạc (Ag) hoặc Vàng (Au) để giảm thiểu điện trở tiếp xúc. Cấu hình tiêu chuẩn là một rơ-le thu nhỏ dạng SPDT (Single Pole Double Throw) với 3 chân: COM (Chung), NO (Thường mở) và NC (Thường đóng).

\subsubsection{Động lực học chuyển mạch và Hiện tượng Dội phím (Bouncing)}

Khi nắp hộp đè lên cần gạt (Actuator), lực này truyền vào và làm uốn cong lò xo lá bên trong. Theo định luật Hooke, lò xo tích lũy thế năng đàn hồi. Ngay khi lực ép đẩy hệ thống vượt qua một "điểm tới hạn" (Operating Point), thế năng được giải phóng đột ngột. Lò xo bung ra, đá tiếp điểm động từ chân NC sang chân NO với vận tốc cực lớn (chỉ vài mili-giây).

Sự chênh lệch giữa Điểm tác động (Operating point) và Điểm nhả (Release point) tạo ra một khoảng trễ vật lý gọi là độ từ trễ cơ học (Mechanical Hysteresis). Đặc tính này vô cùng quan trọng: nó đảm bảo rằng dù nắp hộp có đóng mở một cách chậm chạp hay bị rung lắc nhẹ, tiếp điểm cũng không bao giờ nằm ở trạng thái lấp lửng, ngăn ngừa sự xuất hiện của hồ quang điện.
Tuy nhiên, sự va đập kim loại ở tốc độ cao chắc chắn sẽ gây ra hiện tượng Dội phím (Switch Bouncing) — tại khoảnh khắc đóng tiếp điểm, hai mặt kim loại sẽ nảy lên nảy xuống vài lần ở cấp độ vi mô, sinh ra một chuỗi các xung nhiễu điện tử trong khoảng 10-20ms đầu tiên. Nếu vi điều khiển đọc tín hiệu trong khoảng thời gian này, nó sẽ hiểu nhầm là nắp hộp bị mở/đóng hàng chục lần liên tiếp. Do đó, trong đồ án này, hiện tượng vật lý nêu trên đã được giải quyết triệt để bằng thuật toán Khử rung phần mềm (Software Debouncing) dựa trên bộ đếm thời gian \texttt{millis()} của ESP32, đảm bảo hệ thống chỉ ghi nhận một thao tác duy nhất sau khi trạng thái cơ học đã ổn định hoàn toàn.

\subsection{Module Thời gian thực (RTC) DS3231 và Cơ chế lưu trữ Offline}

\begin{figure}[H]
    \centering
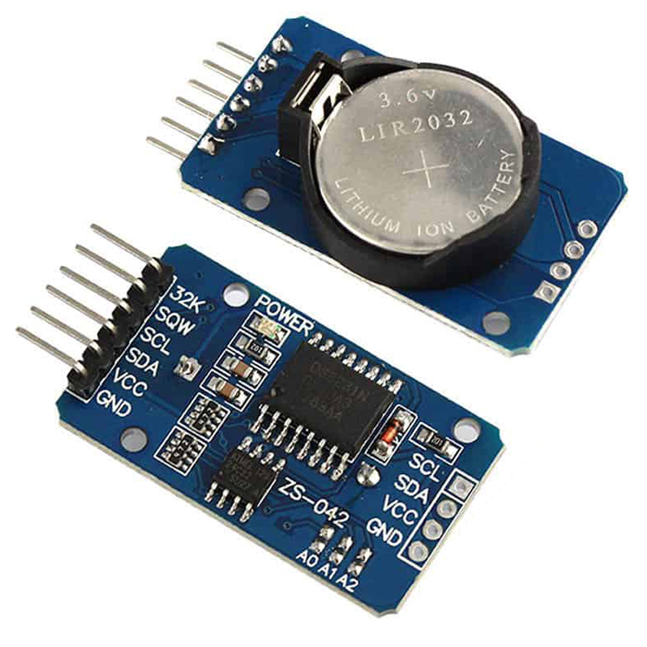
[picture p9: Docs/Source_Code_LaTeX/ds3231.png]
    
    \caption{Module thời gian thực DS3231 tích hợp IC nhớ}
    \label{fig:ds3231}
\end{figure}

\subsubsection{Cấu trúc phần cứng và Bộ dao động bù nhiệt}

DS3231 là một vi mạch đồng hồ thời gian thực (Real-Time Clock) giao tiếp qua chuẩn I2C, được tích hợp sẵn bộ dao động thạch anh bù nhiệt (Temperature-Compensated Crystal Oscillator - TCXO) và một tinh thể thạch anh bên trong vỏ chip. Sự khác biệt lớn nhất của DS3231 so với các dòng RTC cơ bản là khả năng duy trì độ chính xác cực cao trong môi trường nhiệt độ biến đổi.

Ở các bộ dao động thông thường, tần số của thạch anh ($32.768\text{ kHz}$) sẽ bị sai lệch khi nhiệt độ môi trường thay đổi, dẫn đến hiện tượng trôi thời gian (time drift). Để khắc phục, DS3231 tích hợp một cảm biến nhiệt độ bên trong để liên tục đo đạc nhiệt độ của tinh thể thạch anh. Dựa vào giá trị này, vi mạch sẽ tự động điều chỉnh mảng tụ điện (capacitance array) bên trong để bù trừ lại sự sai lệch tần số. Nhờ vậy, sai số của DS3231 chỉ ở mức $\pm 2\text{ ppm}$ (tương đương sai lệch khoảng 1 phút mỗi năm).

Bên cạnh đó, DS3231 có thiết kế đường nguồn dự phòng (pin $V_{BAT}$). Khi nguồn cấp chính ($V_{CC}$) bị ngắt, mạch so sánh nội bộ sẽ tự động chuyển mạch sang nguồn pin dự phòng (Pin CMOS CR2032 3V) để duy trì hoạt động của bộ đếm thời gian mà không làm gián đoạn hệ thống.

\subsubsection{Tổ chức bộ nhớ và Định dạng dữ liệu BCD}

Dữ liệu thời gian bên trong DS3231 được lưu trữ tại các thanh ghi riêng biệt bao gồm: Giây, Phút, Giờ, Thứ, Ngày, Tháng và Năm. Mạch tự động tính toán số ngày trong các tháng có ít hơn 31 ngày và hỗ trợ tự động bù trừ năm nhuận (áp dụng đến năm 2100).

Dữ liệu trong các thanh ghi này được định dạng theo chuẩn BCD. Đây là hệ thống mã hóa số thập phân trong đó mỗi chữ số thập phân được biểu diễn bằng một chuỗi nhị phân 4 bit. Việc sử dụng BCD giúp vi điều khiển trung tâm dễ dàng trích xuất trực tiếp các giá trị hàng chục và hàng đơn vị của thời gian để hiển thị lên màn hình (như OLED) mà không cần thực hiện các phép chia nguyên hay lấy dư phức tạp, giúp tối ưu hóa chu kỳ lệnh của CPU.

\subsubsection{Hệ thống Báo thức kép và Ngắt phần cứng}

DS3231 được trang bị hai thanh ghi báo thức độc lập (Alarm 1 và Alarm 2). Hệ thống báo thức này cho phép lập trình viên thiết lập các mốc thời gian kích hoạt cụ thể (khớp theo giây, phút, giờ hoặc ngày).

Khi giá trị thời gian thực tế đếm đến mốc thời gian đã cài đặt trong thanh ghi Alarm, vi mạch sẽ tự động bật một cờ báo ngắt. Nếu được cấu hình, tín hiệu ngắt này sẽ được xuất ra chân SQW/INT (mức thấp tích cực). Trong các thiết kế hệ thống nhúng tiết kiệm năng lượng, đặc tính này đóng vai trò then chốt: Vi điều khiển chính có thể chuyển vào trạng thái ngủ sâu (Deep-sleep) để bảo toàn năng lượng, và chỉ bị "đánh thức" bởi tín hiệu ngắt phần cứng từ chân INT của DS3231 khi đến chính xác thời điểm cần thực thi nhiệm vụ.

\subsection{Module Quản lý Năng lượng và Tăng áp J5019}

\begin{figure}[H]
    \centering
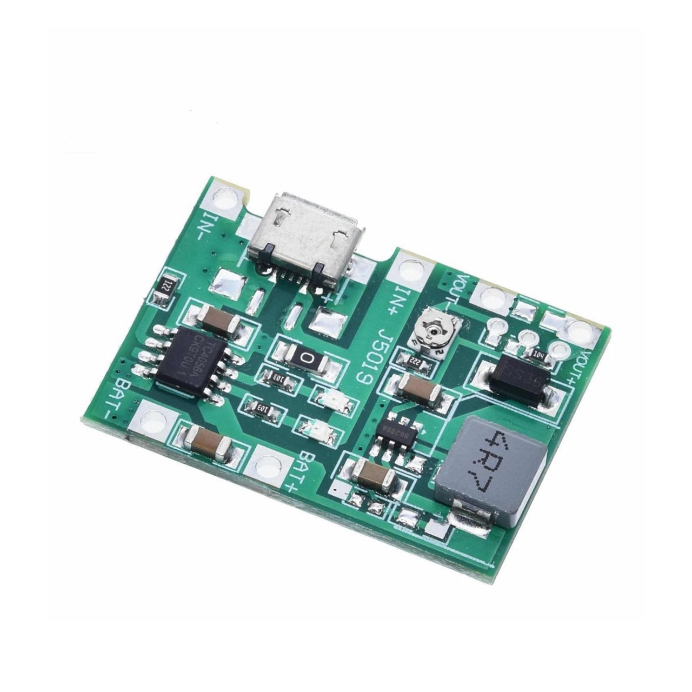
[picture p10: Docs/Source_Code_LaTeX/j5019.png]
    
    \caption{Mạch sạc tích hợp Boost DC-DC J5019}
    \label{fig:j5019}
\end{figure}

\subsubsection{Cấu trúc phần cứng và Tích hợp hệ thống}
Module J5019 là một giải pháp thiết kế phần cứng kết hợp giữa mạch sạc pin Lithium-ion 1 cell (3.7V) và mạch chuyển đổi điện áp nâng áp (DC-DC Boost Converter). Trong các hệ thống IoT nhúng yêu cầu tính liên tục như dự án hộp thuốc thông minh, module này đóng vai trò trọng yếu trong việc đảm bảo vi điều khiển trung tâm ESP32 và các cảm biến ngoại vi luôn được cấp một mức điện áp hoạt động ổn định (tùy chỉnh ở mức 5V hoặc 9V), ngay cả khi điện áp định mức của cell pin suy giảm dần trong chu kỳ xả. Nền tảng board mạch hỗ trợ cấp nguồn đầu vào đa dạng thông qua cổng Micro USB/Type-C hoặc các vị trí hàn trực tiếp, đồng thời cho phép tinh chỉnh điện áp đầu ra linh hoạt thông qua một biến trở tích hợp.

\subsubsection{Nguyên lý Sạc tuyến tính (Linear Charging) và Cơ chế CC/CV}
Khối sạc của module vận hành dựa trên vi mạch chuyên dụng TP4056. Quá trình nạp năng lượng cho pin Lithium được giám sát và điều khiển nghiêm ngặt thông qua thuật toán Dòng không đổi / Áp không đổi (CC/CV - Constant Current / Constant Voltage) nhằm tối ưu hóa tuổi thọ và đảm bảo an toàn hóa học bên trong cell pin:
\begin{itemize}
    \item \textbf{Sạc nhỏ giọt (Trickle Charge):} Khi điện áp pin sụt xuống dưới ngưỡng an toàn (thường là 2.9V), vi mạch chỉ cấp một dòng sạc rất nhỏ (khoảng 10\% dòng định mức) để phục hồi áp từ từ, ngăn ngừa hiện tượng sốc nhiệt và phá vỡ cấu trúc hóa học của pin.
    \item \textbf{Dòng không đổi (Constant Current):} Khi điện áp pin vượt ngưỡng 2.9V, mạch tự động chuyển sang trạng thái bơm dòng tối đa (có thể lên đến 1A tùy thuộc vào điện trở lập trình $R_{PROG}$) để nạp nhanh dung lượng.
    \item \textbf{Áp không đổi (Constant Voltage):} Khi điện áp trên hai cực của pin tiệm cận mức sạc đầy 4.2V, mạch sẽ duy trì ổn định mức áp này trong khi dòng sạc bắt đầu suy giảm theo hàm đồ thị mũ. Quá trình sạc sẽ tự động ngắt hoàn toàn (Termination) khi dòng điện giảm xuống dưới ngưỡng cắt.
\end{itemize}

\subsubsection{Nguyên lý Mạch Tăng áp (DC-DC Boost) và Động lực học Chuyển mạch}
Khối nâng áp ứng dụng kiến trúc chuyển mạch tần số cao, sử dụng IC MT3608 hoạt động ở xung nhịp xấp xỉ 1.2MHz. Việc triển khai tần số chuyển mạch lớn cho phép tối thiểu hóa kích thước vật lý của cuộn cảm (Inductor) và tụ lọc (Capacitor) trên không gian board mạch. Quá trình biến đổi mức điện áp tuân theo chu kỳ của hai pha cơ bản:
\begin{itemize}
    \item \textbf{Pha tích lũy (Switch ON):} Khi MOSFET nội bộ được kích dẫn, dòng điện từ nguồn pin đi qua cuộn cảm xuống mass, khiến cuộn cảm tích lũy năng lượng dưới dạng từ trường.
    \item \textbf{Pha giải phóng (Switch OFF):} Khi MOSFET ngắt, từ trường trong cuộn cảm sụp đổ và sinh ra sức điện động cảm ứng. Điện áp này cộng gộp nối tiếp với điện áp nguồn pin, vượt qua điện áp phân cực của Diode Schottky và xả năng lượng định tuyến vào tụ điện ngõ ra.
\end{itemize}

Trị số điện áp đầu ra được kiểm soát bởi mạng điện trở phân áp (Feedback resistor network) thông qua phương trình:
\begin{equation}
    V_{out} = V_{ref} \times \left(1 + \frac{R_1}{R_2}\right)
\end{equation}
Trong đó, $V_{ref}$ là điện áp tham chiếu nội bộ (thường là 0.6V), $R_1$ và $R_2$ là các trị số điện trở cấu thành trên nhánh phản hồi. Khi triển khai mạch in (PCB) trên phần mềm Altium Designer, quá trình đi dây khu vực này cần tách biệt vùng nhiễu chuyển mạch tần số cao ra khỏi các đường tín hiệu I2C hoặc Logic nhạy cảm để tránh hiện tượng sai số dữ liệu.

\newpage
\begin{center}
    \section{THIẾT KẾ VÀ THỰC HIỆN PHẦN CỨNG}
\end{center}
%Nội dung chương 3
\subsection{Sơ đồ khối tổng quát của hệ thống}
Hệ thống được thiết kế dựa trên sự tương tác giữa 4 khối chức năng chính: Khối nguồn, Khối xử lý trung tâm, Khối ngõ vào và Khối ngõ ra.

\begin{itemize}
    \item \textbf{Khối Nguồn:} Sử dụng pin Lithium-Ion 3.7V kết hợp mạch quản lý năng lượng J5019. Dòng điện từ pin được tăng áp lên mức 5V ổn định để cung cấp năng lượng cho toàn hệ thống.
    \item \textbf{Khối Xử lý trung tâm:} Vi điều khiển ESP32 chịu trách nhiệm thu thập tín hiệu cảm biến, điều khiển ngoại vi hiển thị, xử lý thuật toán thời gian và giao tiếp vô tuyến với hệ thống máy chủ.
    \item \textbf{Khối Ngõ vào:} Bao gồm đồng hồ thời gian thực DS3231 cung cấp mốc thời gian chuẩn xác và công tắc hành trình để nhận diện thao tác đóng hoặc mở nắp hộp. Mạch còn được tích hợp thêm khối chia áp để đo lường dung lượng pin hiện tại.
    \item \textbf{Khối Ngõ ra:} Màn hình OLED hiển thị thông tin trực quan và còi báo động để phát ra âm thanh cảnh báo khi đến cữ thuốc.
\end{itemize}

\begin{figure}[H]
    \centering
    \begin{tikzpicture}[
        scale=0.85, transform shape,
        box/.style = {rectangle, draw=black, thick, fill=blue!10, text width=3.2cm, align=center, minimum height=2.2cm, rounded corners},
        power/.style = {rectangle, draw=black, thick, fill=red!10, text width=3.2cm, align=center, minimum height=1.2cm, rounded corners},
        input/.style = {rectangle, draw=black, thick, fill=green!10, text width=2.8cm, align=center, minimum height=1.2cm, rounded corners},
        output/.style = {rectangle, draw=black, thick, fill=yellow!10, text width=2.8cm, align=center, minimum height=1.2cm, rounded corners},
        arrow/.style = {thick, ->, >=stealth},
        bidi/.style = {thick, <->, >=stealth}
    ]

    % --- KHAI BÁO CÁC KHỐI ---
    
    \node[box] (esp) {\textbf{Khối Xử lý trung tâm} \\ ESP32 NodeMCU};

    \node[power, above=1.2cm of esp] (power) {\textbf{Khối Nguồn} \\ Pin Li-Po 3.7V \\ + Boost J5019};

    % Khối Ngõ vào (Tách xa nhau ra để không đè, tạo không gian cho chữ L)
    \node[input, left=2.5cm of esp, yshift=2.7cm] (rtc) {\textbf{Thời gian thực} \\ Module RTC DS3231};
    \node[input, left=2.5cm of esp, yshift=-2.7cm] (switch) {\textbf{Cảm biến} \\ Công tắc hành trình};

    % Khối Ngõ ra (Tương tự, tách đều lên xuống)
    \node[output, right=2.5cm of esp, yshift=2.7cm] (oled) {\textbf{Khối Hiển thị} \\ Màn hình OLED 0.96 inch};
    \node[output, right=2.5cm of esp, yshift=-2.7cm] (buzzer) {\textbf{Khối Cảnh báo} \\ Còi Buzzer};

    % --- VẼ MŨI TÊN KẾT NỐI (ĐƯỜNG CHỮ L) ---
    
    % Nguồn -> ESP32 (Đường thẳng từ trên xuống)
    \draw[arrow] (power) -- node[anchor=west, font=\small] {5V DC} (esp);
    
    % RTC <-> ESP32 (Chữ L: Từ DƯỚI đáy RTC đi xuống rồi rẽ phải vào mép trái ESP32)
    \draw[bidi] (rtc.south) |- node[above, font=\small, pos=0.75] {I2C} ([yshift=0.6cm]esp.west);
    
    % Switch -> ESP32 (Chữ L: Từ ĐỈNH Switch đi lên rồi rẽ phải vào mép trái ESP32)
    \draw[arrow] (switch.north) |- node[above, font=\small, pos=0.75] {Digital} ([yshift=-0.6cm]esp.west);
    
    % ESP32 -> OLED (Chữ L: Từ mép phải ESP32 đi ngang ra rồi rẽ CẮM LÊN đáy OLED)
    \draw[arrow] ([yshift=0.6cm]esp.east) -| node[above, font=\small, pos=0.25] {I2C} (oled.south);
    
    % ESP32 -> Buzzer (Chữ L: Từ mép phải ESP32 đi ngang ra rồi CẮM XUỐNG đỉnh Buzzer)
    \draw[arrow] ([yshift=-0.6cm]esp.east) -| node[above, font=\small, pos=0.25] {Digital} (buzzer.north);

    \end{tikzpicture}
    \caption{Sơ đồ khối tổng quát hệ thống Hộp Thuốc IoT}
    \label{fig:so_do_khoi_tikz}
\end{figure}

\subsection{Tính toán và lựa chọn linh kiện}
Việc lựa chọn và bổ sung linh kiện được cân nhắc kỹ lưỡng nhằm khắc phục các vấn đề vật lý phát sinh và đảm bảo tính ổn định của thiết bị:
\subsubsection{Vi điều khiển trung tâm ESP32}
Đối với một thiết bị y tế cá nhân phân tán chạy bằng năng lượng pin, vi điều khiển trung tâm đòi hỏi phải cân bằng giữa năng lực tính toán hiệu năng cao và khả năng tiết kiệm năng lượng tối ưu. Bo mạch phát triển ESP32 NodeMCU Devkit V1 được lựa chọn dựa trên các luận cứ kỹ thuật sau:
\begin{itemize}
    \item \textbf{Kiến trúc lõi kép xử lý bất đồng bộ:} Vi xử lý kiến trúc lõi kép 32-bit cho phép phân tách luồng tác vụ chạy ngầm của ngăn xếp giao thức mạng vô tuyến và luồng thuật toán ứng dụng của người dùng trên hai lõi độc lập, giải quyết triệt để hiện tượng nghẽn lệnh hoặc treo hệ thống khi chờ kết nối máy chủ.
    \item \textbf{Cơ chế quản lý năng lượng linh hoạt:} ESP32 hỗ trợ cấu hình hạ xung nhịp hoạt động của CPU xuống mức 80MHz và cung cấp chế độ ngủ sâu. Trong trạng thái ngủ, toàn bộ lõi xử lý và module vô tuyến được ngắt điện hoàn toàn, dòng tiêu thụ giảm xuống mức vi-ampe, đóng vai trò kéo dài chu kỳ sống của pin.
    \item \textbf{Tài nguyên bộ nhớ tích hợp lớn:} Dung lượng bộ nhớ SRAM lớn cho phép xử lý và phân tích các chuỗi dữ liệu định dạng JSON phức tạp từ API đám mây trả về. Đồng thời, bộ nhớ Flash cho phép lưu trữ hệ thống tệp tin tĩnh và hàng đợi dữ liệu lịch sử khi thiết bị rớt mạng.
\end{itemize}

\subsubsection{Hệ thống nguồn và khối đo lường dung lượng pin}
Hệ thống nguồn được thiết kế hướng tới tính bền bỉ, an toàn hóa học và tối ưu không gian cơ khí của thiết bị:
\begin{itemize}
    \item \textbf{Module quản lý sạc và tăng áp J5019:} Linh kiện tích hợp sẵn vi mạch sạc tuyến tính chuyên dụng TP4056 và vi mạch biến đổi nâng áp một chiều chuyển mạch tần số cao MT3608 hoạt động ở xung nhịp 1.2MHz. Sự tích hợp này giúp loại bỏ hoàn toàn việc sử dụng hai module độc lập, tiết kiệm diện tích bo mạch in và giảm thiểu điện cảm ký sinh trên đường dây dẫn nguồn. Khối sạc vận hành theo cơ chế dòng không đổi và áp không đổi, đảm bảo an toàn tuyệt đối cho pin. Khối nâng áp cho phép điều chỉnh ngõ ra ổn định ở mức 5V phục vụ cho đường nguồn chính của hệ thống.
    \item \textbf{Pin nguồn Li-Ion hiệu năng cao:} Thay vì sử dụng các dòng pin Lithium Polymer giá rẻ có độ tin cậy thấp và độ suy hao dung lượng nhanh trên thị trường, đề tài ứng dụng giải pháp tái chế cell pin Lithium-Ion từ các dòng điện thoại thông minh chính hãng đã qua sử dụng. Các cell pin này sở hữu dung lượng thực tế đạt xấp xỉ 2000mAh, tích hợp sẵn mạch bảo vệ chạm chập nguyên bản của nhà sản xuất, đồng thời cung cấp dòng xả đỉnh cực kỳ ổn định. Giải pháp này vừa tối ưu chi phí thi công mạch, vừa đảm bảo độ an toàn chống phồng pin, cháy nổ vượt trội trong quá trình hoạt động dài hạn.
    \item \textbf{Khối bảo vệ nguồn khẩn cấp:} Khi module vô tuyến của ESP32 thực hiện kết nối mạng hoặc giải mã các giao thức bảo mật đám mây, dòng tiêu thụ biên của linh kiện có thể đột ngột vọt lên mức 350mA - 400mA trong khoảng thời gian mili-giây. Để triệt tiêu hiện tượng sụt áp cục bộ trên đường nguồn gây kích hoạt bộ giám sát điện áp thấp nội bộ làm vi điều khiển tự khởi động lại liên tục, một tụ hóa chất lượng cao có trị số 100uF được bổ sung kẹp song song tại ngõ vào nguồn 5V, đóng vai trò như một kho lưu trữ bù dòng tức thời.
    \item \textbf{Cầu phân áp giám sát năng lượng:} Để hệ thống nhận biết mức dung lượng pin hiện tại nhằm đưa ra cảnh báo sạc, điện áp trực tiếp từ cell pin được đưa qua một cầu chia áp gồm hai điện trở có trị số lớn 100k mắc nối tiếp xuống mass. Điện áp pin cực đại ở mức sạc đầy (4.2V) qua cầu phân áp sẽ giảm tuyến tính xuống mức 2.1V, hoàn toàn tương thích với ngưỡng đọc an toàn của bộ chuyển đổi tương tự - số trên chân D34 của ESP32. Việc lựa chọn giá trị điện trở lên đến 100k giúp giới hạn dòng rò tiêu hao qua nhánh đo lường ở mức siêu nhỏ, không làm ảnh hưởng đến tổng dung lượng chung của pin:
    \begin{equation}
        I_{leak} = \frac{V_{bat}}{R_{bat1} + R_{bat2}} = \frac{4.2V}{100k\Omega + 100k\Omega} = 21\mu A
    \end{equation}
\end{itemize}

\subsubsection{Tính toán thời gian vận hành lý thuyết}
Dòng điện tiêu thụ tổng thể của hệ thống được tính toán dựa trên chu kỳ hoạt động đặc thù của một thiết bị nhắc nhở y tế cá nhân:
\begin{itemize}
    \item Dòng điện trung bình ở chế độ hoạt động (Active Mode): $\approx 120$ mA.
    \item Dòng điện trung bình ở chế độ ngủ (Deep-sleep Mode): $\approx 5$ mA (bao gồm dòng tĩnh của module thời gian thực và dòng rò chuyển mạch của cuộn cảm trên mạch tăng áp).
    \item Kịch bản vận hành giả định: Thiết bị thức tổng cộng 30 phút (0.5 giờ) mỗi ngày để thực hiện hiển thị, phát cảnh báo chuông và đồng bộ dữ liệu mạng; thời gian còn lại 23.5 giờ thiết bị nằm ở trạng thái ngủ tiết kiệm năng lượng.
\end{itemize}
Điện năng tiêu thụ định mức trong một ngày của hệ thống được xác định qua phương trình:
\begin{equation}
    C_{day} = (120\text{ mA} \times 0.5\text{ h}) + (5\text{ mA} \times 23.5\text{ h}) = 60\text{ mAh} + 117.5\text{ mAh} = 177.5\text{ mAh}
\end{equation}
Với cell pin Lithium-Ion dung lượng 2000mAh, thời gian hoạt động liên tục lý thuyết của hộp thuốc trước khi cần kết nối bộ sạc là:
\begin{equation}
    T_{operation} = \frac{2000\text{ mAh}}{177.5\text{ mAh/ngày}} \approx 11.27\text{ ngày}
\end{equation}
Kết quả tính toán chứng minh hệ thống hoàn toàn đáp ứng tiêu chuẩn của một thiết bị y tế di động tầm trung, giảm thiểu tần suất phải cắm sạc cho người dùng.

\subsubsection{Module thời gian thực DS3231}
Để đảm bảo tính năng báo thức hoạt động chính xác tuyệt đối kể cả khi mất kết nối mạng, đồng hồ thời gian thực độc lập DS3231 được trang bị với các đặc tính kỹ thuật vượt trội:
\begin{itemize}
    \item \textbf{Bộ dao động thạch anh bù nhiệt:} Tích hợp sẵn cảm biến nhiệt độ nội vi và mảng tụ điện linh hoạt bên trong vỏ chip. Cơ chế này liên tục đo đạc biên độ nhiệt môi trường để hiệu chỉnh tần số dao động của tinh thể thạch anh, khống chế sai số thời gian ở mức cực thấp, không bị hiện tượng lệch giờ do nhiệt độ phòng biến đổi.
    \item \textbf{Cơ chế duy trì nguồn độc lập:} Module được trang bị đường nguồn dự phòng thông qua rào cắm kết nối với pin cúc áo CR2032. Khi nguồn điện chính của hộp thuốc bị ngắt hoàn toàn, vi mạch tự động chuyển đổi sang nguồn pin dự phòng để nuôi bộ đếm thời gian nội bộ, đảm bảo tính toàn vẹn dữ liệu lịch trình.
\end{itemize}

\subsubsection{Cảm biến và ngoại vi hiển thị, cảnh báo}
\begin{itemize}
    \item \textbf{Công tắc hành trình cơ học:} Lựa chọn công tắc dạng đòn bẩy gạt nảy dựa trên cơ cấu quá tâm. Tiếp điểm cơ học SPDT giúp triệt tiêu hoàn toàn dòng điện nuôi ở trạng thái chờ so với cảm biến hồng ngoại. Linh kiện mang lại phản hồi đóng cắt chắc chắn khi đóng mở nắp hộp. Hiện tượng dội phím cơ học phát sinh trong khoảng 10-20ms đầu tiên của tiếp điểm được xử lý dứt điểm bằng bộ lọc phần mềm.
    \item \textbf{Màn hình hiển thị OLED 0.96 inch:} Sử dụng IC điều khiển SSD1306, giao tiếp qua bus số I2C. Công nghệ tự phát sáng tại từng điểm ảnh hữu cơ giúp loại bỏ đèn nền, mang lại độ tương phản cao, góc nhìn rộng phù hợp cho mắt người cao tuổi và mức tiêu thụ dòng cực thấp.
    \item \textbf{Còi cảnh báo chủ động:} Tích hợp sẵn mạch dao động đa hài bên trong vỏ còi. Vi điều khiển chỉ cần xuất mức logic cao từ chân GPIO để cấp nguồn, còi sẽ tự động băm dòng điện thành các xung vuông tần số 2500Hz ổn định, giảm tải hoàn toàn chu kỳ xung phần mềm cho CPU.
\end{itemize}

\subsection{Thiết kế sơ đồ nguyên lý (Schematic)}
Sơ đồ nguyên lý của hệ thống được xây dựng và chuẩn hóa trên công nghệ thiết kế của phần mềm Altium Designer. Toàn bộ cấu trúc mạch tuân thủ nghiêm ngặt nguyên lý mô-đun hóa: tất cả các module chức năng và đường kết nối ngoại vi đều giao tiếp thông qua hệ thống các rào cắm (Header) đực-cái tiêu chuẩn bước chân 2.54mm, hạn chế tối đa việc hàn nhiệt trực tiếp lên thân linh kiện nhạy cảm, giúp bo mạch có tính tùy biến cao và dễ dàng bảo trì.

\begin{figure}[H]
    \centering
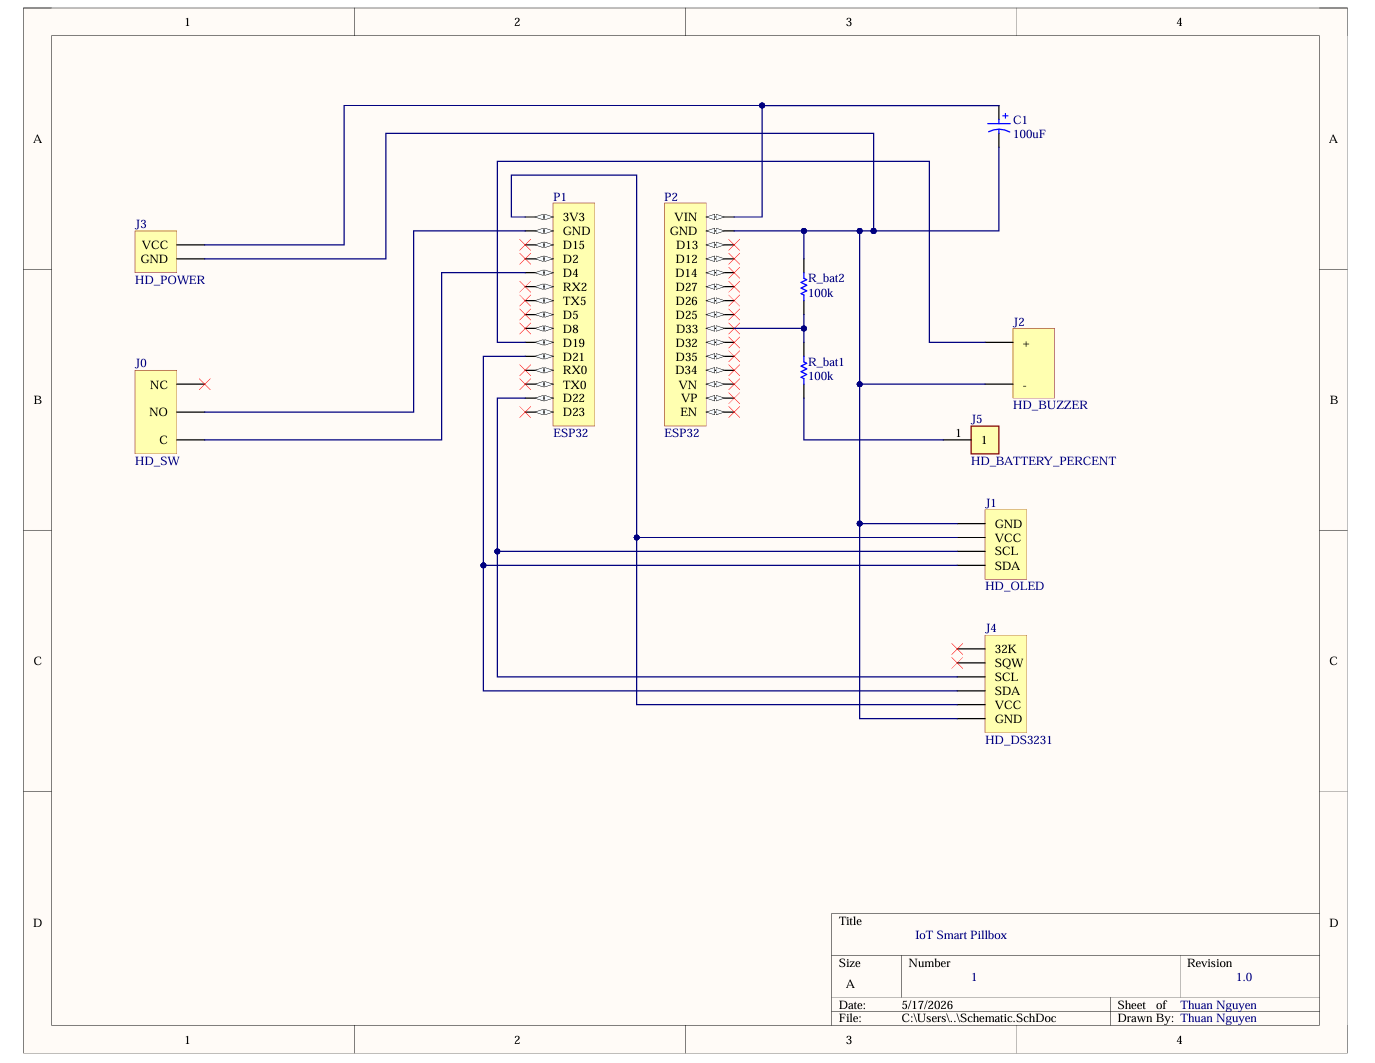
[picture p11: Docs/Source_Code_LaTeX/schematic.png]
    
    \caption{Sơ đồ nguyên lý hệ thống Hộp Thuốc IoT thiết kế trên Altium Designer}
    \label{fig:schematic}
\end{figure}

Sự phân bổ tín hiệu và tổ chức sơ đồ mạch điện được quy hoạch chi tiết như sau:
\begin{itemize}
    \item \textbf{Cụm kết nối nguồn chính và ổn định áp (J3):} Rào cắm J3 nhận nguồn điện một chiều 5V ổn định từ ngõ ra của module sạc tăng áp. Tại đây, tụ hóa lọc nguồn C1 (100uF) được bố trí song song nối từ đường VCC xuống mass chung để dập nhiễu tần số cao và bù dòng. Nguồn điện sau lọc được đưa trực tiếp vào chân VIN của ESP32 nhằm tận dụng IC ổn áp hạ tầng tuyến tính nội vi của bo mạch để tạo ra nguồn 3.3V cấp cho chip core.
    \item \textbf{Cụm giám sát điện áp đầu vào của pin (J5):} Rào cắm J5 kết nối trực tiếp với cực dương của cell pin di động. Đường tín hiệu này được dẫn qua mạng phân áp gồm điện trở $R_{bat1}$ (100k) và $R_{bat2}$ (100k). Điểm giữa của cầu phân áp trích xuất ra một mức điện áp bằng một nửa áp thực tế của pin, đấu nối trực tiếp vào chân đầu vào tương tự D34 của ESP32 phục vụ hàm thuật toán đo lường dung lượng phần trăm pin.
    \item \textbf{Cụm bus số đồng bộ I2C (J1 và J4):} Rào cắm J1 kết nối màn hình hiển thị OLED và rào cắm J4 kết nối module thời gian thực DS3231 được mắc song song trực tiếp trên cùng một cấu trúc bus I2C. Chân dữ liệu hai chiều SDA kết nối vào chân GPIO21, chân xung nhịp đồng bộ SCL kết nối vào chân GPIO22 của vi điều khiển trung tâm. Toàn bộ các linh kiện trên bus đều được nuôi bằng nguồn 3.3V cấp từ chân ra ổn áp của ESP32 nhằm đảm bảo sự đồng chuẩn về biên độ điện áp logic, chống dòng rò phá hủy cổng đệm.
    \item \textbf{Cụm cơ điện giám sát nắp hộp (J0):} Rào cắm J0 giao tiếp với công tắc hành trình. Chân chung của công tắc nối mass hệ thống, chân thường mở nối trực tiếp vào GPIO15 của ESP32. Chân GPIO15 được lập trình cấu hình kích hoạt điện trở kéo lên nội vi, tạo ra trạng thái tích cực mức thấp ổn định khi nắp hộp bị tác động mở ra.
    \item \textbf{Cụm đầu ra phát cảnh báo (J2):} Rào cắm J2 kết nối còi báo động chủ động, nhận dòng lệnh điều khiển đóng cắt logic trực tiếp từ chân GPIO2 của vi điều khiển trung tâm.
\end{itemize}

\subsection{Thiết kế mạch in (PCB Layout)}
Sau khi hoàn thiện kiểm tra lỗi thiết kế trên sơ đồ nguyên lý, cấu trúc mạch in được triển khai và định hình thực tế. Khác với các sản phẩm công nghiệp đi dây tự động siêu nhỏ, bo mạch của đồ án được tính toán hình học hướng đến khả năng tối ưu cho phương pháp gia công ủi mạch và ăn mòn hóa học thủ công.

\subsubsection{Thiết lập quy tắc thiết kế}
Để đảm bảo bo mạch sau khi ủi nhiệt và ăn mòn bằng dung dịch hóa chất không bị đứt mạch, rỗ đồng hay lem thiếc khi hàn tay, các thông số trong bảng quy tắc thiết kế được thiết lập đặc biệt:
\begin{itemize}
    \item \textbf{Độ rộng đường mạch:} Toàn bộ hệ thống đường đi dây dẫn nguồn chính cũng như các đường truyền tín hiệu đều được đẩy độ rộng lên mức rất lớn, dao động từ \textbf{30 mil đến 35 mil}. Kích thước to bản này đảm bảo lớp mực in bám chắc chắn lên phôi đồng, không bị bong tróc dưới nhiệt độ của bàn là và không bị axit lẹm vào lõi.
    \item \textbf{Khoảng cách an toàn:} Khoảng cách an toàn giữa các đường đồng kề nhau được nới rộng tối đa để tránh hiện tượng mực in bị lem dính vào nhau lúc ủi. Đường kính các chân cắm linh kiện của các rào cắm được tăng kích thước và phủ đồng rộng, giúp chân đồng không bị bong ra khỏi phíp sợi thủy tinh khi chịu tác động nhiệt từ mỏ hàn tay.
    \item \textbf{Phủ đồng tiếp mass toàn phần:} Sử dụng kỹ thuật phủ kín lớp đồng trên phần diện tích trống của mạch và nối với mạng mass chung (GND). Giải pháp này vừa giúp rút ngắn thời gian ăn mòn hóa chất do lượng đồng thừa ít, vừa tạo ra một thảm chắn nhiễu điện từ trường hiệu quả.
\end{itemize}

\subsubsection{Hình ảnh thiết kế thực tế}
Dưới đây là chi tiết bố cục hình học 2D và mô phỏng 3D của bo mạch sau khi đã hoàn thiện quá trình đi dây:

\begin{figure}[H]
    \centering
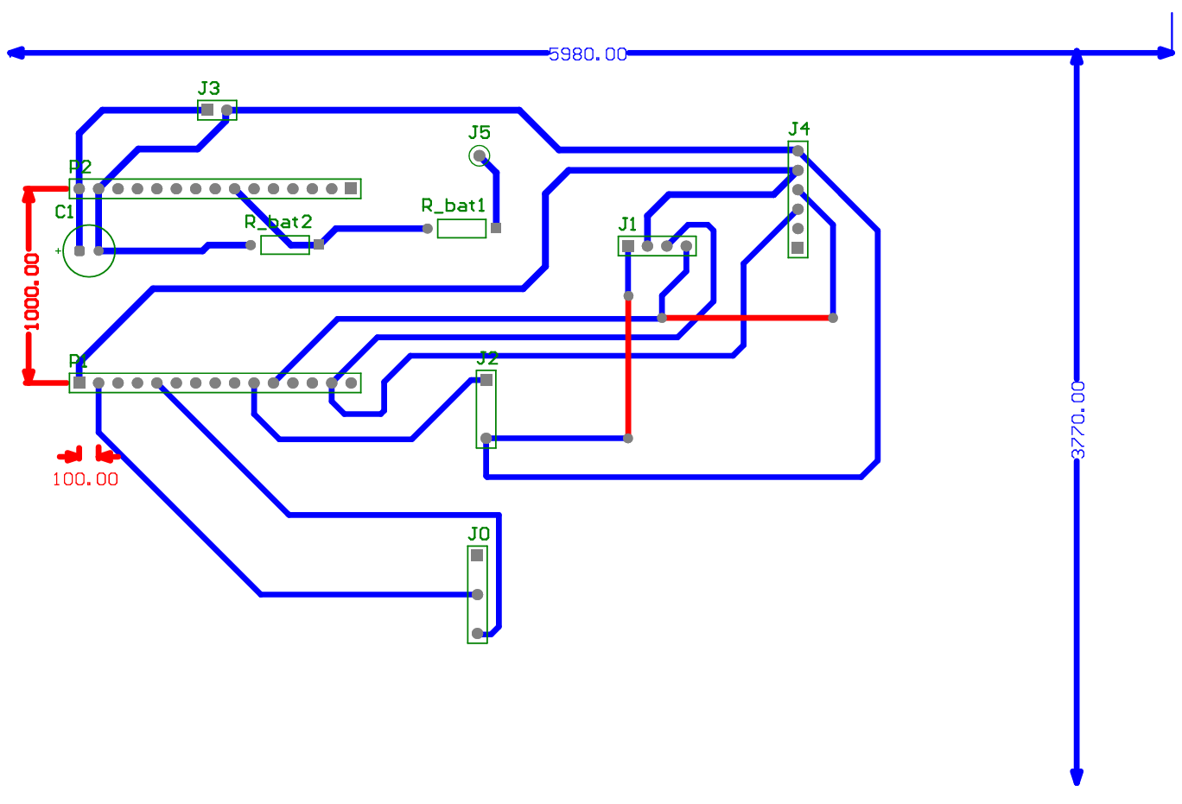
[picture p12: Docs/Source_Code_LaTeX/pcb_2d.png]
    
    \caption{Thiết kế đường mạch in 2D lớp Bottom với độ rộng vệt đồng 30-35 mil}
    \label{fig:pcb_2d}
\end{figure}

\begin{figure}[H]
    \centering
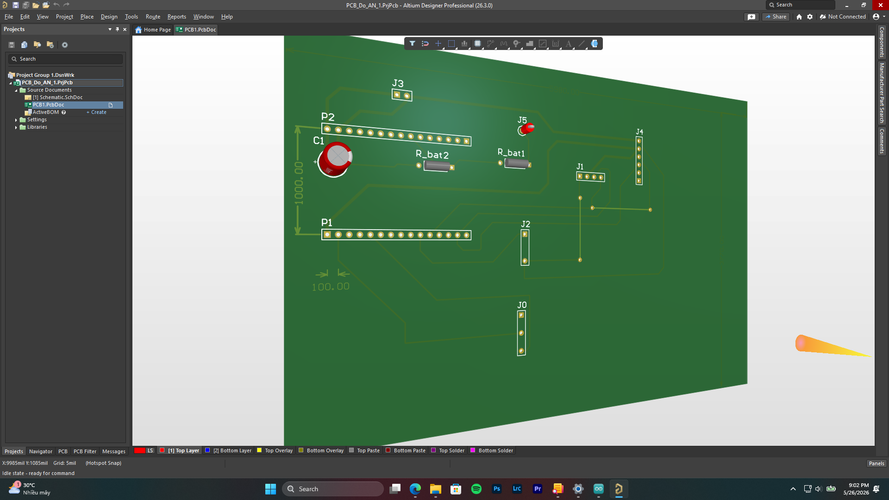
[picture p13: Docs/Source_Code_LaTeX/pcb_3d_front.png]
    
    \caption{Giao diện mô phỏng hình học 3D mặt trước (Top View) của bo mạch}
    \label{fig:pcb_3d_front}
\end{figure}

\begin{figure}[H]
    \centering
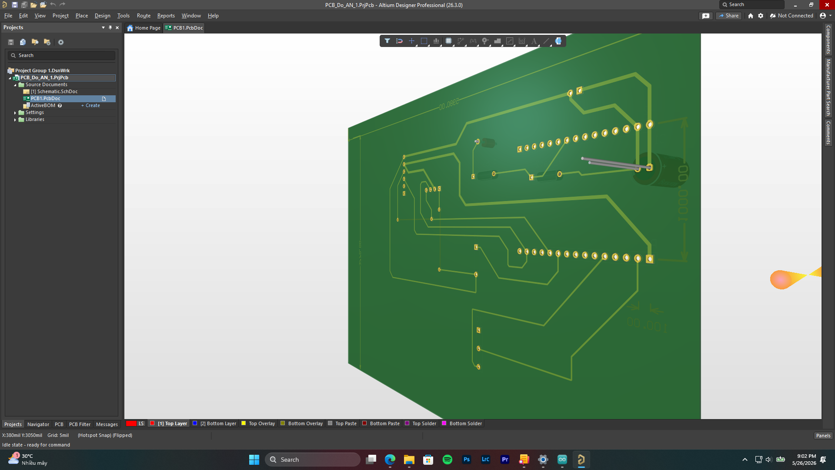
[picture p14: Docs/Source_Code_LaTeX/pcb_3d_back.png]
    
    \caption{Giao diện mô phỏng hình học 3D mặt sau (Bottom View) thể hiện đường mạch}
    \label{fig:pcb_3d_back}
\end{figure}

\subsubsection{Phân tích thông số kích thước và bố cục linh kiện}
Bo mạch được quy hoạch cấu trúc với kích thước bao tổng thể là 5980 mil × 3770 mil (tương đương khoảng $152\text{ mm} \times 96\text{ mm}$), hoàn toàn khớp với ngàm cố định ở đáy hộp thuốc cơ khí. Chiến thuật sắp xếp linh kiện tuân thủ nghiêm ngặt các nguyên lý động lực học dòng điện và chống nhiễu:
\begin{itemize}
    \item \textbf{Quy hoạch không gian vi điều khiển:} Hai dãy rào cắm đỡ khối ESP32 được bố trí song song ở khu vực trung tâm thiên về bên trái với khoảng cách cách lòng chuẩn xác là 1000 mil (25.4 mm), khớp tuyệt đối với kích thước chân của board Devkit V1, giúp triệt tiêu hoàn toàn ứng suất cơ học gây cong chân linh kiện.
    \item \textbf{Bố trí khối nguồn và lọc nhiễu:} Rào cắm nguồn chính được đặt ở góc trên bên trái, sát ngay vị trí chân cấp nguồn của ESP32. Tụ hóa lọc nguồn 100uF được ưu tiên đặt nằm ngay sát vách chân rào cắm và đường nguồn vào vi điều khiển. Việc ép khoảng cách đường mạch nguồn ngắn nhất giúp triệt tiêu điện trở ký sinh của đường dây đồng, cho phép tụ xả dòng bù áp tức thời với hiệu suất cao nhất.
    \item \textbf{Bố trí khối đo lường pin:} Hai điện trở phân áp 100k được đặt kẹp sát cạnh rào cắm đo áp pin và chân đọc tương tự D34. Việc thu hẹp diện tích đi dây giúp cách ly đường tín hiệu đo lường nhạy cảm khỏi vùng nhiễu tần số cao phát ra từ module nguồn.
    \item \textbf{Bố trí cụm bus số I2C và ngõ ra:} Rào cắm màn hình OLED và đồng hồ DS3231 được gom thành một cụm chức năng ở phía bên phải. Việc đặt sát nhau cho phép đường mạch rẽ nhánh bus I2C ngắn nhất, giảm thiểu điện dung ký sinh trên đường truyền. Rào cắm công tắc hành trình được đẩy hẳn xuống góc dưới cùng bên phải mạch để thuận tiện luồn dây điện ra bản lề cơ khí của nắp hộp thuốc.
    \item \textbf{Chiến thuật đi dây đơn lớp:} Toàn bộ hệ thống đường mạch in đều được đi vát một góc 45 độ, loại bỏ góc vuông 90 độ nhằm chống hiện tượng dội sóng tín hiệu và bẫy axit khi ăn mòn mạch. Toàn bộ các đường tín hiệu được thiết kế chạy liền mạch trên một lớp duy nhất mà không cần sử dụng bất kỳ lỗ xuyên mạch nào, gia tăng độ bền cơ học cho hệ thống.
\end{itemize}

\subsection{Thiết kế cơ khí và vỏ hộp}
\subsubsection{Lựa chọn phôi vỏ hộp và thông số hình học}
Để hiện thực hóa cấu trúc bao che cho sản phẩm một cách nhanh chóng và tối ưu hóa chi phí sản xuất, đề tài lựa chọn giải pháp sử dụng vỏ hộp nhựa kỹ thuật đúc sẵn được phân phối thương mại. Vỏ hộp được chế tạo từ chất liệu nhựa ABS dẻo dai, sở hữu độ bền cơ học cao, khả năng cách điện tuyệt đối và bề mặt nhẵn mịn thẩm mỹ. Với kích thước hình học tổng thể được lựa chọn phù hợp với không gian bo mạch in, vỏ hộp đảm bảo tính nhỏ gọn của một thiết bị y tế cá nhân di động, đồng thời cung cấp cấu trúc nắp đóng mở linh hoạt, tạo điều kiện thuận lợi cho việc bố trí và cơ chế tác động của công tắc hành trình.

\subsubsection{Giải pháp thiết kế phân tầng không gian nội bộ}
Nhằm cách ly hoàn toàn hệ thống linh kiện điện tử nhạy cảm khỏi môi trường lưu trữ y tế và tối ưu hóa diện tích sử dụng, không gian bên trong hộp được quy hoạch theo cơ cấu phân tầng hai lớp thông qua một vách ngăn kỹ thuật nằm ngang:
\begin{itemize}
    \item \textbf{Tầng kỹ thuật phía dưới:} Là nơi định vị cố định bo mạch điều khiển trung tâm và khối pin lưu trữ năng lượng Lithium-Ion. Việc đặt các cấu kiện điện tử và nguồn điện ở đáy hộp giúp hạ thấp trọng tâm vật lý, đảm bảo thiết bị vận hành vững chãi trên mặt phẳng, đồng thời bảo vệ mạch điện khỏi các tác động cơ học trực tiếp từ bên ngoài.
    \item \textbf{Vách ngăn trung gian và cơ chế hành trình:} Một tấm vách ngăn bằng vật liệu nhựa nhẹ được lót ở giữa nhằm che chắn toàn bộ tầng kỹ thuật bên dưới. Tại vị trí bản lề, vách ngăn được khoét một khe hở nhỏ để luồn hệ thống đòn bẩy gạt nảy của công tắc hành trình nhô lên phía trên. Khi nắp hộp đóng lại, nắp sẽ tì đè trực tiếp lên cần gạt công tắc; khi nắp mở ra, công tắc lập tức giải phóng tiếp điểm để kích hoạt luồng dữ liệu cảnh báo.
    \item \textbf{Tầng lưu trữ phía trên:} Toàn bộ khoảng không gian còn lại phía trên vách ngăn được tận dụng làm ngăn chứa thuốc sạch sẽ, thông thoáng. Thiết kế phân tầng này giúp người bệnh dễ dàng lấy thuốc mà không tiếp xúc vật lý với mạch điện, ngăn ngừa hoàn toàn nguy cơ rò rỉ điện hoặc làm hư hỏng các đường dây tín hiệu bên trong.
\end{itemize}

\begin{figure}[H]
    \centering
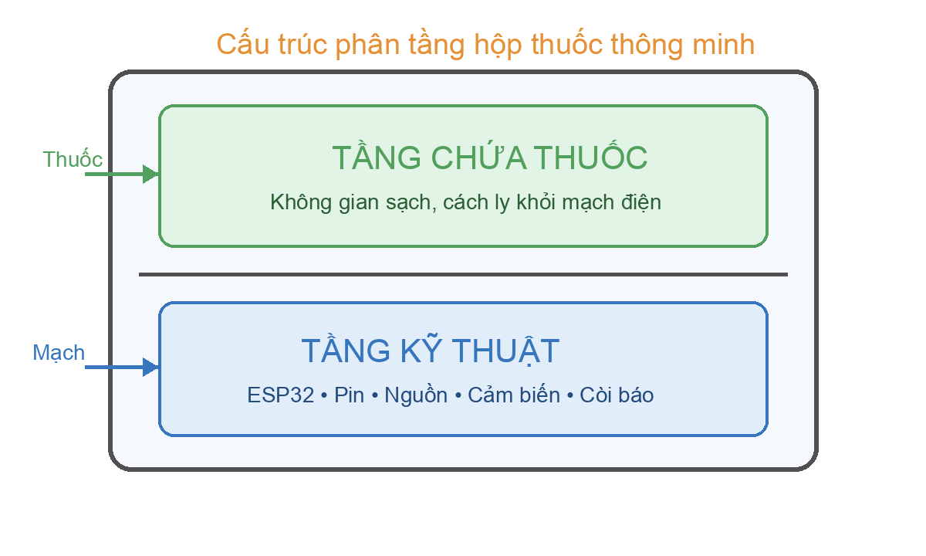
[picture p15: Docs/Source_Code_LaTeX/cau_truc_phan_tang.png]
    
    \caption{Giải pháp phân tầng với ngăn kỹ thuật phía dưới và không gian chứa thuốc phía trên}
    \label{fig:cau_truc_phan_tang}
\end{figure}

\subsubsection{Gia công cơ khí ngoại vi vỏ hộp}
Quá trình gia công cắt gọt các cổng giao tiếp trên phôi hộp ABS đúc sẵn được thực hiện bằng công cụ mài cắt kỹ thuật số cầm tay, đảm bảo độ chuẩn xác và tính thẩm mỹ cao:
\begin{itemize}
    \item \textbf{Cửa sổ hiển thị mặt trước:} Được khoét một ô trống hình chữ nhật có kích thước tương thích hoàn toàn với khung hiển thị của màn hình hữu cơ tự phát quang, giúp tối ưu hóa góc nhìn cho người dùng.
    \item \textbf{Khe cắm nguồn mặt bên:} Được dũa định hình chính xác tại vị trí hông hộp, cho phép luồn đầu cáp sạc kết nối trực tiếp vào cổng Type-C của vi điều khiển mà không cần mở toàn bộ cấu trúc thiết bị.
    \item \textbf{Hệ thống thoát âm cảnh báo:} Khu vực đối diện khối còi báo động được khoan các lỗ thoát âm biên độ nhỏ, hỗ trợ sóng âm lan tỏa ra môi trường với cường độ định mức cao nhất mà vẫn ngăn chặn được bụi bẩn lọt vào bên trong.
\end{itemize}

\begin{figure}[H]
    \centering
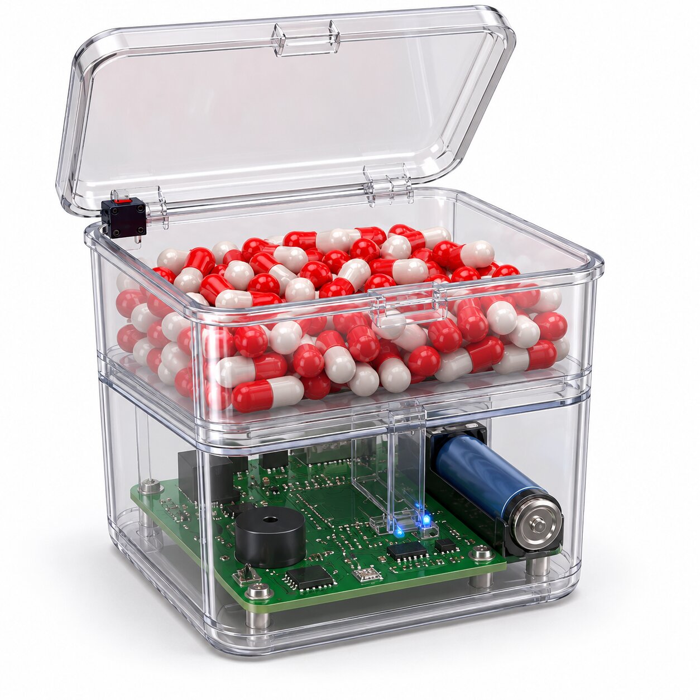
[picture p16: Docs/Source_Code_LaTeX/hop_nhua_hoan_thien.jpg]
    
    \caption{Ngoại quan tổng thể của hệ thống sau khi hoàn thiện gia công cơ khí trên phôi hộp đúc sẵn (Ảnh minh hoạ)}
    \label{fig:hop_nhua_hoan_thien}
\end{figure}

\subsubsection{Gia công cơ khí và hoàn thiện bề mặt}
Quá trình gia công cơ khí vỏ hộp đòi hỏi độ chính xác cao để đảm bảo tính thẩm mỹ và công năng của thiết bị. Các thao tác cắt gọt được thực hiện bằng công cụ mài cắt đa năng tốc độ cao:
\begin{itemize}
    \item \textbf{Mặt trước:} Được gia công khoét rãnh hình chữ nhật với kích thước chuẩn xác, đóng vai trò làm cửa sổ hiển thị cho màn hình hữu cơ tự phát quang, đảm bảo góc nhìn rộng và không bị lẹm thông tin.
    \item \textbf{Mặt bên:} Được khoan và dũa định hình cửa ngõ giao tiếp cho cổng nạp năng lượng Type-C, cho phép người dùng dễ dàng kết nối bộ sạc mà không cần tháo rời vỏ hộp.
    \item \textbf{Cửa thoát âm:} Vị trí đối diện còi báo động được gia công các lỗ thoát âm nhỏ, giúp sóng âm định hướng khuếch đại ra môi trường bên ngoài mà không làm suy giảm cường độ âm thanh cảnh báo.
\end{itemize}

\begin{figure}[H]
    \centering
     % Bạn chèn ảnh chụp vỏ hộp đã đóng nắp hoàn thiện đẹp đẽ vào đây
    \caption{Tổng thể ngoại quan thiết bị sau khi hoàn thiện gia công cơ khí}
    \label{fig:vo_hop_hoan_thien}
\end{figure}

\subsection{Dự toán kinh phí và Đánh giá hiệu quả kinh tế hệ thống}
\subsubsection{Bảng tổng hợp danh mục vật tư và kinh phí sản xuất}
Để đánh giá tính khả thi về mặt kinh tế và khả năng triển khai thực tiễn của đề tài, toàn bộ chi phí vật tư cấu thành nên một nguyên mẫu thử nghiệm của hệ thống được tổng hợp chi tiết trong Bảng \ref{tab:bom_chiphi}.

\begin{table}[H]
    \centering
    \vspace{0.2cm}
    \renewcommand{\arraystretch}{1.3} % Giãn dòng đảm bảo độ thông thoáng cho bảng dữ liệu
    \resizebox{\textwidth}{!}{% Ép kích thước bảng vừa vặn với chiều rộng văn bản, chống tràn lề vật lý
    \begin{tabular}{|c|l|c|r|r|}
        \hline
        \textbf{STT} & \textbf{Tên linh kiện / Vật tư kỹ thuật} & \textbf{Số lượng} & \textbf{Đơn giá (VNĐ)} & \textbf{Thành tiền (VNĐ)} \\ \hline
        1 & Vi điều khiển cấu trúc lõi kép ESP32 NodeMCU 30-pin & 1 & 125.000 & 125.000 \\ \hline
        2 & Màn hình hiển thị công nghệ OLED I2C SSD1315 & 1 & 47.000 & 47.000 \\ \hline
        3 & Module thời gian thực độc lập DS3231 (kèm nguồn dự phòng) & 1 & 40.000 & 40.000 \\ \hline
        4 & Mạch quản lý nạp và tăng áp tích hợp J5019 & 1 & 30.000 & 30.000 \\ \hline
        5 & Phíp đồng sợi thủy tinh tráng quang phục vụ gia công & 1 & 25.000 & 25.000 \\ \hline
        6 & Vật tư phụ (Rào cắm, dây dẫn tín hiệu, thiếc hàn, công tắc) & 1 & 20.000 & 20.000 \\ \hline
        7 & Còi báo động cấu trúc áp điện chủ động & 1 & 9.000 & 9.000 \\ \hline
        8 & Tụ điện hóa lọc nguồn 100$\mu$F - 16V & 1 & 750 & 750 \\ \hline
        9 & Điện trở màng carbon dán 100k$\Omega$ & 2 & 250 & 500 \\ \hline
        \multicolumn{4}{|r|}{\textbf{TỔNG CHI PHÍ KHÁI TOÁN:}} & \textbf{297.250} \\ \hline
    \end{tabular}%
    }
    \caption{Bảng tổng hợp kinh phí sản xuất nguyên mẫu hệ thống}
    \label{tab:bom_chiphi}
\end{table}

\subsubsection{Phân tích và đánh giá mức chi phí sản xuất sản phẩm}
Dựa trên số liệu thực tế tại Bảng \ref{tab:bom_chiphi}, tổng kinh phí ước tính để hoàn thiện phần cứng cho một đơn vị sản phẩm nguyên mẫu là dưới 300.000 VNĐ. Đối với một hệ thống nhúng có khả năng thực thi các tác vụ mạng phức tạp, đồng bộ hóa thời gian thực và quản lý cơ sở dữ liệu phân tán, mức chi phí này phản ánh sự hợp lý trong việc tính toán và lựa chọn cấu kiện. Các luận điểm kỹ thuật - kinh tế được làm rõ như sau:

\begin{itemize}
    \item \textbf{Tối ưu hóa tài nguyên phần cứng trung tâm:} Thành phần chiếm tỷ trọng ngân sách lớn nhất là vi điều khiển trung tâm ESP32 (xấp xỉ 42\% tổng chi phí). Tuy nhiên, đây là giải pháp tối ưu thay vì lựa chọn các kiến trúc vi điều khiển lõi đơn kết hợp với module thu phát vô tuyến rời. Sự tích hợp này không chỉ giảm thiểu không gian cơ khí mà còn loại bỏ các sai số xung đột giao tiếp dòng dữ liệu, đảm bảo hiệu suất xử lý không đồng bộ của hai tầng tác vụ ứng dụng và truyền thông.
    \item \textbf{Đảm bảo tính độc lập và an toàn dữ liệu y tế:} Khối hiển thị dữ liệu và khối thời gian thực độc lập chiếm khoảng 29\% tổng giá trị cấu thành. Việc duy trì module thời gian thực bù nhiệt là yêu cầu bắt buộc nhằm duy trì hoạt động định thời chính xác kể cả trong kịch bản mất liên lạc mạng toàn phần, bảo vệ tính toàn vẹn của phác đồ điều trị và ngăn ngừa rủi ro trôi giờ báo thức.
    \item \textbf{Ứng dụng giải pháp khai thác năng lượng tuần hoàn:} Bộ nguồn lưu trữ năng lượng từ pin Lithium-Ion không phát sinh chi phí trong danh mục vật tư do đề tài hướng tới việc tận dụng và tái chuẩn hóa các cell pin từ thiết bị di động cũ. Phương án này giúp giảm giá thành hệ thống, đồng thời kiểm chứng khả năng vận hành dòng xả ổn định của các khối năng lượng tái chế trong các hệ thống nhúng công suất thấp.
\end{itemize}

\subsubsection{Chiến lược tối ưu hóa chi phí khi triển khai sản xuất hàng loạt}
Mức chi phí hiện tại được tối ưu cho giai đoạn nghiên cứu và phát triển nguyên mẫu thử nghiệm. Khi chuyển dịch sang giai đoạn thương mại hóa và chế tạo ở quy mô công nghiệp với số lượng lớn, giá thành sản xuất trên một đơn vị thiết bị có thể giảm đáng kể thông qua các giải pháp kỹ thuật chuyên sâu:

\begin{itemize}
    \item \textbf{Tối ưu hóa kiến trúc mạch nguyên khối:} Loại bỏ hoàn toàn việc sử dụng bo mạch phát triển đầu cuối NodeMCU và các module ngoại vi độc lập liên kết qua các cổng rào cắm vật lý. Thiết kế sơ đồ nguyên lý mới sẽ tích hợp trực tiếp chip xử lý hệ thống trên một bo mạch chủ duy nhất. Các linh kiện thụ động và IC quản lý nguồn chuyên dụng như mạch sạc tuyến tính hay mạch chuyển đổi nâng áp chuyển mạch tần số cao sẽ được thiết kế dạng dán bề mặt, giúp tối thiểu hóa kích thước hình học PCB và giảm chi phí nhân công lắp ráp thủ công.
    \item \textbf{Ứng dụng các dòng vi xử lý chuyên biệt giá rẻ:} Thay thế module lõi kép bằng các kiến trúc lõi đơn cấu trúc RISC-V có tích hợp Wi-Fi thế hệ mới, giúp giảm chi phí phôi bán dẫn trung tâm xuống hơn một nửa trong khi vẫn đáp ứng đầy đủ các thuật toán biên mã hóa HTTPS và đẩy dữ liệu đám mây.
    \item \textbf{Tác động từ hiệu ứng quy mô kinh tế:} Khi triển khai đặt hàng cấu kiện bán dẫn, linh kiện thụ động dán và đặt dây chuyền gia công dán mạch tự động với số lượng lớn, chi phí khấu hao thiết kế và đơn giá vật tư đầu vào sẽ giảm theo hình học, cho phép hạ giá thành sản xuất thương mại ước tính xuống dưới 150.000 VNĐ một đơn vị sản phẩm.
\end{itemize}

\newpage
\begin{center}
    \section{THIẾT KẾ VÀ THỰC HIỆN PHẦN MỀM}
\end{center}
%Nội dung chương 4
\subsection{Các thư viện phần mềm cốt lõi và chức năng tích hợp}
Hệ thống phần mềm trên ESP32 được phát triển dựa trên nền tảng Arduino IDE. Để tối ưu hóa quá trình lập trình và tương tác với phần cứng, đề tài sử dụng các thư viện mã nguồn mở chuyên dụng sau:

\begin{itemize}
    \item \textbf{\texttt{WiFiManager.h}:} Thư viện quản lý cấu hình mạng động.
    \begin{itemize}
        \item \textit{Hàm sử dụng:} \texttt{autoConnect()} kích hoạt điểm truy cập cục bộ (AP) và Captive Portal khi rớt mạng, cho phép người dùng nhập mật khẩu Wi-Fi mới mà không cần nạp lại mã nguồn.
    \end{itemize}
    
    \item \textbf{\texttt{WiFiClientSecure.h} \& \texttt{HTTPClient.h}:} Thư viện giao thức vô tuyến.
    \begin{itemize}
        \item \textit{Hàm sử dụng:} \texttt{setInsecure()} bỏ qua xác thực chứng chỉ chuỗi để tiết kiệm RAM. Lệnh \texttt{GET()} và \texttt{POST()} dùng để đóng gói và đẩy/nhận dữ liệu y tế với máy chủ Google Apps Script.
    \end{itemize}
    
    \item \textbf{\texttt{Adafruit\_SSD1306.h} \& \texttt{Adafruit\_GFX.h}:} Thư viện đồ họa màn hình.
    \begin{itemize}
        \item \textit{Hàm sử dụng:} \texttt{display()} xuất bộ đệm nội dung ra màn hình OLED. Hàm \texttt{ssd1306\_command()} dùng để can thiệp trực tiếp vào thanh ghi ép xung giảm sáng (Deep Dimming).
    \end{itemize}
    
    \item \textbf{\texttt{RTClib.h}:} Thư viện giao tiếp đồng hồ thời gian thực DS3231.
    \begin{itemize}
        \item \textit{Hàm sử dụng:} \texttt{now()} trích xuất thời gian hiện tại để hiển thị. Hàm \texttt{setAlarm1()} nạp cấu hình cữ thuốc vào thanh ghi để sinh ngắt phần cứng.
    \end{itemize}
    
    \item \textbf{\texttt{Preferences.h}:} Thư viện quản lý bộ nhớ tĩnh (Non-Volatile Storage).
    \begin{itemize}
        \item \textit{Hàm sử dụng:} \texttt{begin()} khởi tạo phân vùng nhớ Flash. Hàm \texttt{putString()} và \texttt{getString()} dùng để ghi/đọc mảng dữ liệu lịch sử uống thuốc khi hệ thống bị mất kết nối Wi-Fi.
    \end{itemize}
    
    \item \textbf{\texttt{NTPClient.h}:} Thư viện giao thức đồng bộ thời gian mạng.
    \begin{itemize}
        \item \textit{Hàm sử dụng:} \texttt{update()} và \texttt{getEpochTime()} dùng để kéo mốc thời gian chuẩn từ máy chủ \texttt{pool.ntp.org} về bù trừ sai số cho mạch DS3231 mỗi khi thiết bị trực tuyến.
    \end{itemize}
\end{itemize}

\subsection{Lưu đồ giải thuật hàm khởi tạo (Setup)}

Hàm khởi tạo được thực hiện một lần duy nhất khi thiết bị được cấp nguồn. Trọng tâm của thuật toán này là Cơ chế ưu tiên ngoại tuyến. Thiết bị sẽ luôn trích xuất lịch trình cũ từ bộ nhớ Flash trước khi thử kết nối mạng. Điều này đảm bảo hệ thống vẫn hoạt động trơn tru (dựa trên dữ liệu cũ) ngay cả khi không có kết nối Wi-Fi.

\begin{figure}[H]
    \centering
    \begin{tikzpicture}[
   scale=0.8,             % Thu nhỏ còn 70% kích thước gốc
    transform shape,       % Bắt buộc phải có để các node và chữ thu nhỏ theo
    node distance=1.2cm,   % Giảm khoảng cách giữa các khối
        >=stealth,
        font=\sffamily\small,
        % Định dạng các khối
        startstop/.style={rectangle, rounded corners=15pt, draw=black, thick, fill=gray!20, minimum width=3.5cm, minimum height=0.8cm, text centered, font=\bfseries},
        decision/.style={diamond, aspect=2.5, draw=black, thick, fill=yellow!10, text width=3cm, text centered, inner sep=0pt},
        process/.style={rectangle, draw=black, thick, fill=blue!5, text width=7.5cm, align=left, minimum height=1cm, inner sep=6pt},
        highlight/.style={rectangle, draw=black, thick, fill=green!10, text width=7.5cm, align=left, minimum height=1cm, inner sep=6pt},
        arrow/.style={thick, ->},
        line/.style={thick}
    ]

    % --- 1. KHAI BÁO CÁC KHỐI ---
    \node[startstop] (start) {Setup};

    \node[process, below=0.8cm of start] (proc1) {
        \textbf{Khởi tạo phần cứng:}\\
        - Cấu hình chân I/O \\
        - Bật giao tiếp I2C
    };

    % Khối nhấn mạnh việc đọc Flash trước khi kết nối mạng
    \node[highlight, below=0.8cm of proc1] (proc2) {
        \textbf{Khôi phục dữ liệu dự phòng:}\\
        - Đọc lịch uống thuốc lưu sẵn trong Flash
    };

    % BỔ SUNG KHỐI KHỞI TẠO WIFI Ở ĐÂY
    \node[process, below=0.8cm of proc2] (wifi_init) {
        \textbf{Khởi tạo kết nối mạng:}\\
        - Bắt đầu kết nối Wi-Fi \\
        - Khởi động bộ đếm thời gian chờ
    };

    \node[decision, below=0.8cm of wifi_init] (dec1) {Kết nối Wi-Fi\\thành công?};

    % Nhánh Online
    \node[process, right=1.5cm of dec1] (proc_online) {
        \textbf{Chế độ Online (Cập nhật mới):}\\
        - Đồng bộ giờ NTP cập nhật RTC\\
        - Tải lịch mới nhất từ máy chủ Cloud
    };

    % Nhánh Offline
    \node[process, fill=orange!10, below=0.8cm of dec1] (proc_offline) {
        \textbf{Chế độ Offline (Sự cố mạng):}\\
        - Bỏ qua mạng, hoạt động\\
        bằng lịch cũ đã nạp từ Flash
    };

    \node[startstop, below=0.8cm of proc_offline] (end) {Kết thúc Setup};

    % --- 2. VẼ ĐƯỜNG MŨI TÊN CHÍNH ---
    \draw[arrow] (start) -- (proc1);
    \draw[arrow] (proc1) -- (proc2);
    \draw[arrow] (proc2) -- (wifi_init);
    \draw[arrow] (wifi_init) -- (dec1);

    % Nhánh Đúng (Sang phải)
    \draw[arrow] (dec1) -- node[above, font=\scriptsize] {Đúng} (proc_online);
    
    % Nhánh Sai (Đi thẳng xuống)
    \draw[arrow] (dec1) -- node[left, font=\scriptsize] {Sai / Hết thời gian chờ} (proc_offline);

    % Về đích
    \draw[arrow] (proc_offline) -- (end);

    % Đường gộp từ nhánh Online xuống đích (Vẽ đường chữ L)
    \draw[arrow] (proc_online.south) |- (end.east);

    \end{tikzpicture}
    \caption{Trình tự khởi tạo hệ thống, nhấn mạnh cơ chế xử lý ngoại tuyến (Offline)}
    \label{fig:luu_do_setup}
\end{figure}

\subsection{Lưu đồ giải thuật vòng lặp chính (Main Loop)}

Thuật toán của hệ thống được thiết kế theo kiến trúc Non-blocking, sử dụng bộ đếm thời gian thực để chia sẻ tài nguyên CPU cho 4 luồng độc lập. Lưu đồ Hình \ref{fig:luu_do_loop} mô tả logic xử lý của hệ thống bằng ngôn ngữ tự nhiên, tập trung vào bản chất luồng dữ liệu thay vì các dòng lệnh phức tạp, giúp người đọc dễ dàng nắm bắt nguyên lý hoạt động:

\begin{figure}[H]
    \centering
    \begin{tikzpicture}[
        node distance=1.2cm and 1.5cm,
        >=stealth,
        font=\sffamily\small,
        % Định dạng các khối
        startstop/.style={rectangle, rounded corners=15pt, draw=black, thick, fill=gray!20, minimum width=3cm, minimum height=0.8cm, text centered, font=\bfseries},
        decision/.style={diamond, aspect=2.5, draw=black, thick, fill=yellow!10, text width=3cm, text centered, inner sep=0pt},
        process/.style={rectangle, draw=black, thick, fill=blue!5, text width=5cm, align=left, minimum height=1cm, inner sep=6pt},
        arrow/.style={thick, ->},
        line/.style={thick}
    ]

    % --- 1. KHAI BÁO CÁC KHỐI ---
    \node[startstop] (start) {Bắt đầu vòng lặp};

    % Task 1
    \node[decision, below=0.8cm of start] (dec1) {Đủ chu kỳ 1 giây?};
    \node[process, right=1.5cm of dec1] (proc1) {
        - Cập nhật giờ lên OLED\\
        - Quét danh sách báo thức
    };

    % Task 2
    \node[decision, below=1cm of dec1] (dec2) {Đang có báo thức?};
    \node[process, right=1.5cm of dec2] (proc2) {
        - Phát xung Buzzer\\
        - Nếu > 5 phút: Ghi "Bỏ cữ"
    };

    % Task 3
    \node[decision, below=1cm of dec2] (dec3) {Trạng thái nắp sau 30p?};
    \node[process, right=1.5cm of dec3] (proc3) {
        - Mở: Ghi "Uống trễ"\\
        - Đóng: Ghi "Đóng nắp"
    };

    % Task 4
    \node[decision, below=1cm of dec3] (dec4) {Đến hạn đồng bộ?};
    \node[process, right=1.5cm of dec4] (proc4) {
        - Tải lịch mới từ Cloud
    };

    % Điểm neo kết thúc
    \node[coordinate, below=0.8cm of dec4] (end) {};

    % --- 2. VẼ ĐƯỜNG TRỤC CHÍNH (XUỐNG DƯỚI) ---
    \draw[arrow] (start) -- (dec1);
    \draw[arrow] (dec1) -- node[left, font=\scriptsize] {Sai} (dec2);
    \draw[arrow] (dec2) -- node[left, font=\scriptsize] {Sai} (dec3);
    \draw[arrow] (dec3) -- node[left, font=\scriptsize] {Sai} (dec4);
    \draw[line]  (dec4) -- node[left, font=\scriptsize] {Sai} (end);

    % --- 3. VẼ ĐƯỜNG NHÁNH (SANG PHẢI) ---
    \draw[arrow] (dec1) -- node[above, font=\scriptsize] {Đúng} (proc1);
    \draw[arrow] (dec2) -- node[above, font=\scriptsize] {Đúng} (proc2);
    \draw[arrow] (dec3) -- node[above, font=\scriptsize] {Đúng} (proc3);
    \draw[arrow] (dec4) -- node[above, font=\scriptsize] {Đúng} (proc4);

    % --- 4. VẼ ĐƯỜNG GỘP TRỞ LẠI TRỤC CHÍNH ---
    \draw[arrow] (proc1.south) |- ($(dec1.south)!0.5!(dec2.north)$);
    \draw[arrow] (proc2.south) |- ($(dec2.south)!0.5!(dec3.north)$);
    \draw[arrow] (proc3.south) |- ($(dec3.south)!0.5!(dec4.north)$);
    \draw[arrow] (proc4.south) |- (end);

    % --- 5. VẼ ĐƯỜNG LẶP LẠI (VÒNG SANG TRÁI MỘT KHOẢNG RỘNG) ---
    \draw[arrow] (end) -- ++(-3.5,0) |- node[right, pos=0.25, font=\scriptsize\itshape] {Lặp lại liên tục} (start.west);

    \end{tikzpicture}
    \caption{Lưu đồ giải thuật các luồng xử lý bên trong vi điều khiển ESP32}
    \label{fig:luu_do_loop}
\end{figure}

\subsection{Giải thuật tối ưu hóa năng lượng màn hình (Deep Dimming)}
Để kéo dài thời lượng pin cho hệ thống, đồ án triển khai giải thuật điều chế độ sáng mờ tầng sâu (Deep Dimming) cho khối hiển thị OLED thay vì chỉ giảm độ tương phản bằng phần mềm thông thường. Giải thuật can thiệp trực tiếp vào các thanh ghi phần cứng của IC SSD1306 nhằm ép dòng điện rò rỉ về mức tối thiểu khi thiết bị rảnh rỗi.

\textbf{Cơ chế can thiệp phần cứng:}
\begin{itemize}
    \item \textbf{Thanh ghi tiền nạp điện tích (Pre-charge Period - 0xD9):} Ép chu kỳ nạp mồi của tụ ký sinh trên điểm ảnh xuống mức thấp nhất (0x11), triệt tiêu hoàn toàn sự tiêu hao năng lượng từ pha nạp mồi điện áp.
    \item \textbf{Thanh ghi điện áp nền (VCOMH Deselect Level - 0xDB):} Điều chỉnh điện áp phân cực của các đường quét dòng rảnh rỗi về 0, loại bỏ dòng rò trên các pixel không được kích hoạt.
    \item \textbf{Thanh ghi độ sáng (Contrast Control - 0x81):} Khống chế dòng định thiên về mức 0, duy trì độ phản xạ lờ mờ vừa đủ đọc trong bóng râm.
\end{itemize}

\textbf{Logic vận hành trong hệ thống:}
Giải thuật sử dụng bộ định thời \texttt{millis()} để giám sát tương tác vật lý. Nếu sau 30 giây hệ thống không ghi nhận trạng thái mở nắp hoặc báo thức, vi điều khiển lập tức nạp chuỗi lệnh Deep Dimming, kéo dòng tiêu thụ của màn hình từ $\sim 20$mA xuống ngưỡng dưới $2$mA. Ngược lại, khi phát hiện tín hiệu từ công tắc hành trình hoặc RTC, các thông số định mức được tái nạp, đưa màn hình bừng sáng 100\% ngay lập tức để phục vụ cảnh báo y tế.

\subsection{Giao tiếp và Quản lý dữ liệu qua Google Sheets}

Hệ thống ứng dụng kiến trúc Serverless, trong đó Google Sheets đóng vai trò là một Cơ sở dữ liệu (Database) và Google Apps Script (GAS) đóng vai trò là Application Programming Interface (API) Backend để xử lý logic nội bộ.

\subsubsection{Thuật toán ghi nhận sự kiện cơ bản}
Khi có các sự kiện vật lý xảy ra, vi điều khiển ESP32 gửi yêu cầu \texttt{HTTP GET} kèm các tham số hành động (\texttt{action=Mo\_Nap}, \texttt{Bo\_Thuoc},...) lên GAS. Máy chủ sẽ tự động trích xuất dấu thời gian thực (Timestamp) theo múi giờ GMT+7 và ghi nối tiếp (appendRow) vào bảng tính. 

\subsubsection{Thuật toán phân tích ngoại lệ (Logic "Uống trễ")}
Đây là một trong những điểm nhấn kỹ thuật của phần mềm. Trong thực tế, bệnh nhân có thể quên uống thuốc đúng giờ, nhưng lại nhớ ra và uống bù sau đó vài chục phút. Nếu chỉ ghi nhận máy móc, dữ liệu sẽ bị rời rạc. Để khắc phục, một thuật toán "Cửa sổ thời gian quy hồi" được triển khai trên máy chủ GAS:
\begin{enumerate}
    \item Khi nhận được lệnh \texttt{Uong\_Tre} từ thiết bị, GAS không ghi ngay dòng mới mà kích hoạt vòng lặp quét ngược cơ sở dữ liệu từ dưới lên trên.
    \item Thuật toán tìm kiếm dòng trạng thái "Bỏ thuốc" gần nhất. Tại dòng này, chuỗi văn bản thời gian được bóc tách (Parse) ngược trở lại thành đối tượng \texttt{Date} tiêu chuẩn.
    \item Hệ thống tính toán độ lệch thời gian ($\Delta t$) giữa thời điểm hiện tại và mốc báo "Bỏ thuốc". Nếu $\Delta t \le 60$ phút (3.600.000 ms), hệ thống sẽ \textbf{Ghi đè (Overwrite)} trực tiếp lên dòng dữ liệu cũ, đổi trạng thái thành "Uống trễ" và cập nhật lại mốc giờ uống thực tế.
\end{enumerate}
Cơ chế này giúp làm sạch dữ liệu nhiễu, cung cấp cho bác sĩ một báo cáo tuân thủ y tế chính xác nhất.

\begin{figure}[H]
    \centering
    \begin{tikzpicture}[
        node distance=1.2cm and 1.2cm,
        >=stealth,
        font=\sffamily\small,
        % Định dạng các khối
        startstop/.style={rectangle, rounded corners=15pt, draw=black, thick, fill=gray!20, minimum width=3cm, minimum height=0.8cm, text centered, font=\bfseries},
        decision/.style={diamond, aspect=2, draw=black, thick, fill=yellow!10, text width=2.8cm, text centered, inner sep=0pt, font=\scriptsize},
        process/.style={rectangle, draw=black, thick, fill=blue!5, text width=4.2cm, align=left, minimum height=1cm, inner sep=6pt, font=\scriptsize},
        arrow/.style={thick, ->},
        line/.style={thick}
    ]

    % --- 1. KHAI BÁO CÁC KHỐI ---
    \node[startstop] (start) {action = "Uong\_Tre"};

    \node[process, below=0.8cm of start] (read) {Tải toàn bộ dữ liệu Sheet vào mảng 2 chiều (Data Array)};

    \node[process, fill=orange!10, below=0.8cm of read] (loop) {\textbf{Vòng lặp (Bottom-Up):}\\ Quét ngược từ dòng cuối cùng lên dòng 1};

    \node[decision, below=0.8cm of loop] (dec_status) {Cột B có bằng\\ "Bỏ thuốc"?};

    \node[decision, right=1cm of dec_status] (dec_time) {Khoảng cách $\Delta t \le 60$ phút?};

    \node[process, right=1cm of dec_time] (overwrite) {\textbf{Hành động Ghi đè:}\\ 1. Đổi "Bỏ thuốc" $\rightarrow$ "Uống trễ"\\ 2. Cập nhật mốc giờ uống bù\\ 3. Break (Thoát vòng lặp)};

    \node[process, below=1cm of dec_status] (append) {\textbf{Hành động Thêm mới:}\\ (Kết thúc lặp không tìm thấy)\\ Thêm 1 dòng log "Uống trễ" mới ở cuối bảng};

    \node[process, fill=green!10, below=0.8cm of overwrite] (push) {\textbf{Push Notification:}\\ Gửi thông báo [INFO] về Telegram Bot};

    \node[startstop, right=1.5cm of append, yshift=-2cm] (end) {Trả về trạng thái SUCCESS};

    % --- 2. VẼ ĐƯỜNG MŨI TÊN ---
    \draw[arrow] (start) -- (read);
    \draw[arrow] (read) -- (loop);
    \draw[arrow] (loop) -- (dec_status);

    % Nhánh xử lý trạng thái
    \draw[arrow] (dec_status) -- node[above, font=\scriptsize] {Đúng} (dec_time);
    \draw[line] (dec_status.west) -- ++(-1,0) |- node[right, pos=0.25, font=\scriptsize\itshape] {Sai (Duyệt dòng trên)} (loop.west);

  % Nhánh xử lý thời gian
    \draw[arrow] (dec_time) -- node[above, font=\scriptsize] {Đúng} (overwrite);
    \draw[arrow] (dec_time.north) |- node[above, pos=0.75, font=\scriptsize\itshape] {Sai (Bỏ qua)} (loop.east);

    % Thoát vòng lặp thất bại
    \draw[arrow] (dec_status) -- node[left, font=\scriptsize] {Duyệt hết mảng} (append);

    % Gộp luồng về đích
    \draw[arrow] (overwrite) -- (push);
    \draw[arrow] (push) |- (end);
    \draw[arrow] (append) -- (end);

    \end{tikzpicture}
    \caption{Lưu đồ thuật toán xử lý ngoại lệ "Uống trễ" (Tìm kiếm ngược Bottom-Up)}
    \label{fig:uong_tre_flow}
\end{figure}

\subsection{Cơ chế lưu trữ dữ liệu ngoại tuyến vào bộ nhớ tĩnh}
Để đảm bảo tính toàn vẹn của dữ liệu giám sát y tế trong kịch bản mất kết nối mạng toàn phần, hệ thống triển khai một cơ chế lưu trữ hàng đợi ngoại tuyến dựa trên phân vùng bộ nhớ tĩnh không bốc hơi của vi điều khiển. 

\textbf{Cơ chế đóng gói và tổ chức hàng đợi lưu trữ:}
Khi tiến trình gửi dữ liệu lên điện toán đám mây phát hiện trạng thái mất liên lạc vô tuyến, vi điều khiển lập tức chuyển hướng dòng dữ liệu sang chế độ dự phòng. Thông tin về hành vi tương tác cùng dấu mốc thời gian thực hiện hành lấy từ mạch định thời độc lập được ghép nối thành một cấu trúc đồng bộ. Chuỗi dữ liệu này được ghi trực tiếp vào phân vùng bộ nhớ tĩnh của chip dưới dạng các cặp khóa và giá trị định danh. Hệ thống duy trì một biến đếm lưu giữ số lượng bản ghi tồn đọng, đóng vai trò điều hướng chỉ số để xếp chồng các sự kiện theo tuần tự thời gian, ngăn ngừa hiện tượng ghi đè làm mất mát dữ liệu của người bệnh.

\textbf{Logic giải tỏa hàng đợi khi phục hồi kết nối:}
Trong chu kỳ quét của vòng lặp hệ thống, trạng thái liên lạc vô tuyến được giám sát liên tục. Ngay khi mạng Internet được tái lập và xác thực ổn định, vi điều khiển sẽ kích hoạt tiến trình giải phóng bộ nhớ đệm. Hệ thống thực hiện đọc tuần tự các bản ghi từ bộ nhớ tĩnh theo chỉ số từ cũ nhất đến mới nhất để đồng bộ hóa ngược lên máy chủ trang tính. Sau khi nhận được tín hiệu phản hồi xác nhận lưu trữ thành công từ đám mây, vi điều khiển tiến hành xóa sạch phân vùng dữ liệu phụ, đồng thời hoàn tác biến đếm hàng đợi về mức số không để giải phóng hoàn toàn không gian nhớ cho các chu kỳ rớt mạng tiếp theo.

\subsection{Hệ thống tương tác hai chiều qua Telegram Bot}

Thay vì chỉ gửi cảnh báo một chiều, nền tảng Telegram Bot trong đồ án được thiết kế để hoạt động song công (Full-duplex), vừa đóng vai trò là \textit{Hệ thống Cảnh báo (Push)} vừa là \textit{Cổng Truy vấn Thống kê (Pull)}.

\subsubsection{Cơ chế Cảnh báo Chủ động (Push Notifications)}
Quá trình gửi tin nhắn không đi trực tiếp từ mạch lên Telegram nhằm giảm tải mã hóa cho ESP32. Khi máy chủ GAS xử lý xong các lệnh ghi log vào Google Sheets, nó sẽ đồng thời gọi phương thức \texttt{UrlFetchApp} tới API của Telegram để đẩy thông báo về điện thoại người nhà.

\textbf{Cấu trúc mã tạo tin nhắn trên máy chủ:}
\begin{verbatim}
var message = "<b>[!] CẢNH BÁO CHƯA UỐNG THUỐC</b>\n" +
              "----------------------------\n" +
              " <b>Thời gian:</b> " + currentTimestampStr + "\n" +
              "<i>Bệnh nhân bỏ lỡ một cữ thuốc! Vui lòng kiểm tra.</i>";
\end{verbatim}
Các tin nhắn sử dụng chuẩn định dạng HTML của Telegram để in đậm (\texttt{<b>}) thông tin then chốt. Sự kiện "Bỏ thuốc" sử dụng ký hiệu cảnh báo \texttt{[!]}, trong khi sự kiện "Mở nắp" đúng giờ sử dụng ký hiệu xác nhận \texttt{[OK]}.

\subsubsection{Cơ chế Webhook Truy vấn Dữ liệu (Pull Requests)}
Để người nhà có thể kiểm tra tình trạng uống thuốc bất cứ lúc nào mà không cần mở trình duyệt, hệ thống thiết lập một kết nối \textbf{Webhook} định tuyến trực tiếp từ máy chủ Telegram về hàm \texttt{doPost(e)} của Google Apps Script.

\begin{figure}[H]
    \centering
    \begin{tikzpicture}[
        node distance=1.8cm,
        >=stealth,
        font=\sffamily\small,
        startstop/.style={rectangle, rounded corners=12pt, draw=black, thick, fill=gray!20, minimum width=6cm, minimum height=0.8cm, text centered, font=\bfseries},
        process/.style={rectangle, draw=black, thick, fill=green!10, text width=6.2cm, inner sep=8pt}
    ]

    % 1. Khai báo các khối (Xếp thẳng hàng dọc)
    \node[startstop] (user) {Người dùng (App Telegram)};
    \node[startstop, below=1.5cm of user] (tele) {Máy chủ Telegram (Bot API)};
    
    % Khối GAS được tích hợp lời diễn giải ở nửa dưới
    \node[process, below=1.5cm of tele] (gas) {
        \centering \bfseries Google AppsScript (Hàm doPost)\\[1ex]
        \hrule\vspace{1ex}
        \raggedright \normalfont \footnotesize
        - Bóc tách lệnh từ JSON payload\\
        - Kích hoạt thuật toán thống kê mảng\\
        - Định dạng kết quả thành chuỗi Text
    };
    
    \node[startstop, below=1.5cm of gas] (sheet) {Cơ sở dữ liệu (Google Sheets)};

    % 2. Vẽ các đường mũi tên (Đã thu hẹp khoảng cách xshift=1.0cm)
    % LƯỢT ĐI (Mũi tên đi xuống, nằm bên phải)
    \draw[->, thick] ([xshift=1.0cm]user.south) -- node[right, align=left] {1. Gửi lệnh (\texttt{/homnay})} ([xshift=1.0cm]tele.north);
    
    \draw[->, thick] ([xshift=1.0cm]tele.south) -- node[right, align=left] {2. Webhook Trigger} ([xshift=1.0cm]gas.north);
    
    \draw[->, thick] ([xshift=1.0cm]gas.south) -- node[right, align=left] {3. Truy xuất \& Ghi log} ([xshift=1.0cm]sheet.north);

    % LƯỢT VỀ (Mũi tên đi lên, nằm bên trái)
    \draw[->, thick] ([xshift=-1.0cm]sheet.north) -- node[left, align=right] {4. Trả kết quả thống kê} ([xshift=-1.0cm]gas.south);
    
    \draw[->, thick] ([xshift=-1.0cm]gas.north) -- node[left, align=right] {5. API \texttt{sendMessage}} ([xshift=-1.0cm]tele.south);
    
    \draw[->, thick] ([xshift=-1.0cm]tele.north) -- node[left, align=right] {6. Hiển thị tin nhắn} ([xshift=-1.0cm]user.south);

    \end{tikzpicture}
    \caption{Lưu đồ quá trình xử lý lệnh tương tác hai chiều qua Webhook}
    \label{fig:telegram_webhook}
\end{figure}

Hệ thống hỗ trợ các tập lệnh tra cứu thông minh như \texttt{/homnay}, \texttt{/tuannay}, \texttt{/thangnay}. Khi nhận được lệnh, hàm \texttt{doPost} sẽ tính toán ngay lập tức tỷ lệ tuân thủ, số lần uống, số lần bỏ lỡ trong khoảng thời gian tương ứng và phản hồi về khung chat chỉ trong vòng dưới 2 giây.

Bên cạnh hàm \texttt{doPost()} chịu trách nhiệm xử lý các yêu cầu từ cấu trúc Webhook của Telegram, hàm \texttt{doGet()} trên nền tảng đám mây Google Apps Script đóng vai trò là một cổng giao tiếp ứng dụng xử lý các truy vấn bất đồng bộ theo phương thức cấu trúc GET. Khối chức năng này vận hành dựa trên nguyên lý phân tích tham số định tuyến được đính kèm trực tiếp trên đường dẫn URL từ phía thiết bị gửi lên. 

Khi nhận được tín hiệu truy cập, hàm \texttt{doGet()} tiến hành bóc tách tham số hành động để phân loại tác vụ cần xử lý. Đối với các yêu cầu cập nhật lịch trình từ vi điều khiển, hàm thực hiện truy vấn vùng nhớ trên bảng tính Google Sheets, đóng gói danh sách mốc thời gian thành một chuỗi dữ liệu chuẩn hóa và phản hồi trực tiếp về tầng ứng dụng của thiết bị. Đối với các sự kiện ghi nhận lịch sử hoặc kiểm tra trạng thái kết nối từ giao diện quản trị, hàm \texttt{doGet()} đóng vai trò như một bộ điều phối dữ liệu, cho phép ghi nối tiếp các dòng trạng thái kèm dấu thời gian thực hoặc tính toán khoảng lệch thời gian để xác thực tính liên tục của nhịp tim hệ thống. Cơ chế này giúp tối ưu hóa băng thông truyền thông, giảm tải chu kỳ xử lý mã hóa cho các thiết bị đầu cuối và đảm bảo tính toàn vẹn dữ liệu cho toàn bộ hệ sinh thái lưu trữ đám mây.

% Ghi chú: Chụp ảnh màn hình lúc bạn gõ lệnh /homnay và bot trả lời kết quả
\begin{figure}[H]
    \centering
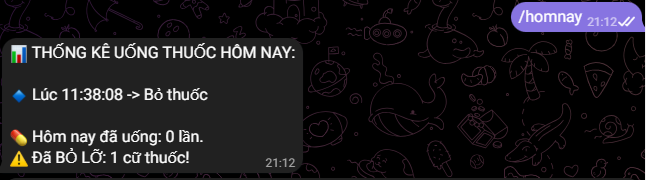
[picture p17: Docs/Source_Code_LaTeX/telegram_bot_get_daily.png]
    
    \caption{Giao diện truy vấn thống kê thời gian thực trên Telegram Bot}
    \label{fig:telegram_ui}
\end{figure}

\subsubsection{Cơ chế Báo cáo tự động định kỳ}

Trong các hệ thống thiết bị IoT chạy pin, việc duy trì kết nối mạng liên tục để canh đúng một mốc thời gian cố định trong ngày (ví dụ: 20h00) nhằm gửi báo cáo tổng kết là một sự lãng phí tài nguyên năng lượng rất lớn. Thậm chí, nếu tại thời điểm đó thiết bị mất điện hoặc rớt mạng, bản báo cáo sẽ không bao giờ được gửi đi. Để giải quyết triệt để vấn đề này, đề tài đã chuyển giao hoàn toàn tác vụ tổng hợp báo cáo cho hệ thống máy chủ đám mây thông qua tính năng Trình kích hoạt thời gian thực của Google Apps Script.

Cơ chế này hoạt động hoàn toàn độc lập với trạng thái (Online/Offline) của hộp thuốc phần cứng. Về mặt thuật toán, một hàm xử lý chuyên biệt (ví dụ: \texttt{sendDailySummary()}) được lập trình trên máy chủ với nhiệm vụ tự động quét toàn bộ cơ sở dữ liệu trong ngày, bóc tách và đếm số lượng các trạng thái "Đã uống", "Uống trễ", và "Bỏ thuốc". Sau đó, hàm sẽ định dạng các số liệu này thành một báo cáo hoàn chỉnh và gọi giao diện lập trình ứng dụng (API) của Telegram để đẩy tin nhắn về thiết bị di động của người quản lý.

Về mặt cấu hình triển khai, hệ thống sử dụng công cụ điều phối tác vụ nội bộ của Google. Trình kích hoạt được thiết lập với các thông số cấu hình tiêu chuẩn như sau:
\begin{itemize}
    \item \textbf{Nguồn sự kiện:} Dựa trên thời gian, đảm bảo máy chủ tự động đánh thức đoạn mã mà không cần bất kỳ tác động ngoại vi nào.
    \item \textbf{Loại trình kích hoạt:} Chu kỳ lặp lại theo ngày.
    \item \textbf{Khung thời gian thực thi:} Cấu hình trong khoảng 20:00 đến 21:00 (múi giờ GMT+7).
\end{itemize}

\begin{figure}[H]
    \centering
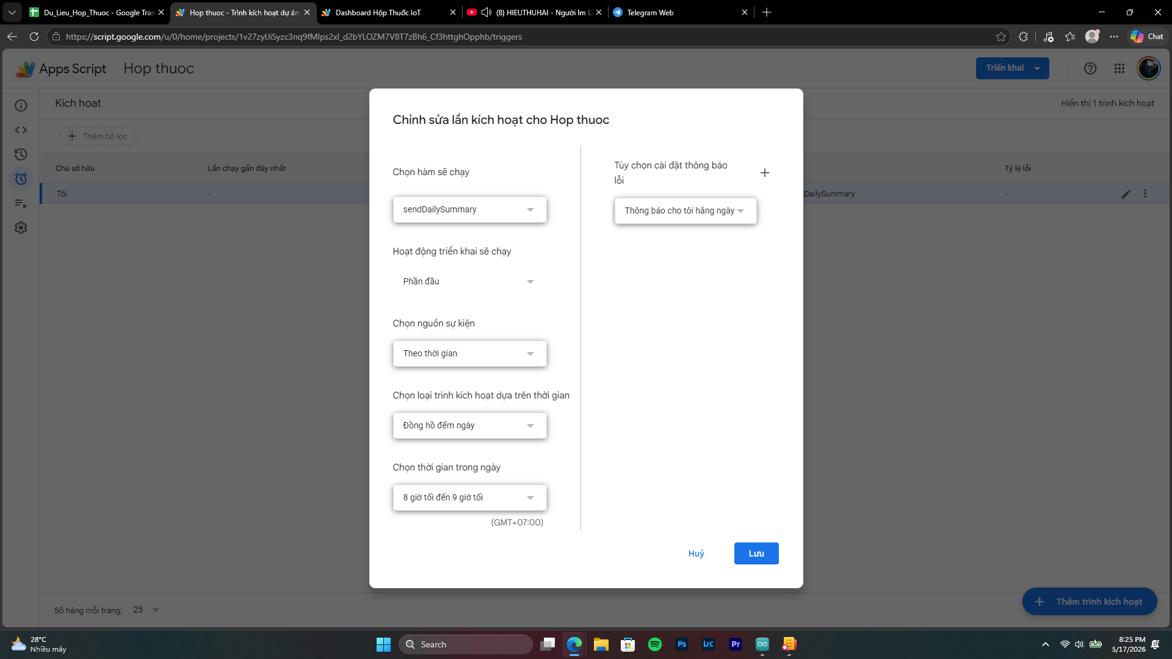
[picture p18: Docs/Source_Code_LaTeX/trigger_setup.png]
     % Thay tên file ảnh chụp màn hình cài đặt Trigger của bạn vào đây
    \caption{Giao diện cấu hình Trình kích hoạt thời gian trên hệ thống Google Apps Script}
    \label{fig:trigger_setup}
\end{figure}

Sự kết hợp giữa kịch bản lệnh trên máy chủ và trình kích hoạt tự động giúp hoàn thiện hệ sinh thái chăm sóc y tế khép kín. Người nhà bệnh nhân luôn nhận được bản tóm tắt tình hình tuân thủ phác đồ điều trị vào mỗi buổi tối một cách chính xác và ổn định nhất, tối ưu hóa triệt để vai trò của điện toán đám mây trong mô hình Internet vạn vật.

\subsection{Thiết kế Giao diện Quản lý trên nền Web}

Bên cạnh hệ thống cảnh báo qua tin nhắn Telegram, đề tài phát triển một trang quản trị chuyên dụng, phục vụ nhu cầu tra cứu và thiết lập phác đồ uống thuốc của bác sĩ hoặc người nhà. Trang mạng này được khởi tạo thông qua dịch vụ giao diện HTML của nền tảng máy chủ Google, giúp hệ thống không cần phụ thuộc vào dịch vụ lưu trữ bên thứ ba.

\subsubsection{Giao diện Giám sát theo Dòng thời gian}
Dựa trên tư vấn của giảng viên hướng dẫn, việc giám sát y tế yêu cầu cái nhìn tổng quan về "xu hướng tuân thủ" của bệnh nhân. Do đó, thay vì chỉ tra cứu dữ liệu đơn lẻ, trang quản trị được thiết kế chức năng tra cứu theo một khoảng thời gian (Từ ngày - Đến ngày).

Dữ liệu thô từ bảng tính được máy chủ phân tích, nhóm các sự kiện "Mở nắp" và "Đóng nắp" thành một cữ "Đã uống", sau đó thuật toán sẽ tự động sắp xếp theo trình tự thời gian tiến dần (từ cũ nhất đến mới nhất). Giao diện hiển thị được thiết kế theo dạng Dòng thời gian với các nhãn trạng thái trực quan:
\begin{itemize}
    \item \textbf{Màu xanh (Đã uống):} Xác nhận bệnh nhân đã tuân thủ đúng cữ thuốc.
    \item \textbf{Màu đỏ (Bỏ cữ):} Cảnh báo các cữ thuốc bị bỏ lỡ.
\end{itemize}

% GHI CHÚ: Chèn ảnh chụp trang web phần hiển thị dòng thời gian vào đây
\begin{figure}[H]
    \centering
    
    \caption{Giao diện tra cứu lịch sử uống thuốc dạng Dòng thời gian}
    \label{fig:dashboard_timeline}
\end{figure}

\subsubsection{Giao diện Thiết lập Báo thức}
Trang quản trị cung cấp một phân hệ chuyên biệt cho phép bác sĩ điều trị hoặc người nhà thiết lập, tinh chỉnh và quản lý phác đồ uống thuốc của bệnh nhân từ xa. Giao diện được thiết kế trực quan với các thành phần chọn giờ chuẩn xác và bộ nút bấm cho phép tùy biến chu kỳ lặp lại theo từng ngày trong tuần.

Về mặt xử lý dữ liệu, khi người dùng hoàn tất thiết lập và ra lệnh lưu, trình duyệt web không gửi dữ liệu thô mà tiến hành tuần tự hóa toàn bộ danh sách báo thức thành một chuỗi ký tự được chuẩn hóa (ví dụ: \texttt{08:00|1234560,20:00|12345}). Kỹ thuật đóng gói dữ liệu này giúp tối ưu hóa không gian lưu trữ trên hệ thống máy chủ, khi toàn bộ phác đồ phức tạp chỉ chiếm dụng một ô nhớ duy nhất. Đồng thời, cấu trúc dữ liệu phân tách bằng các ký tự đặc biệt giúp vi điều khiển ESP32 dễ dàng tải về và bóc tách mảng thông tin bằng các hàm xử lý chuỗi cơ bản mà không làm tràn bộ nhớ vi mạch.

\begin{figure}[H]
    \centering
    % Bạn hãy cắt riêng khu vực "Cài đặt lịch uống thuốc" trên web (chỗ có các nút T2, T3, T4...) lưu thành file web_alarm.png để chèn vào đây nhé
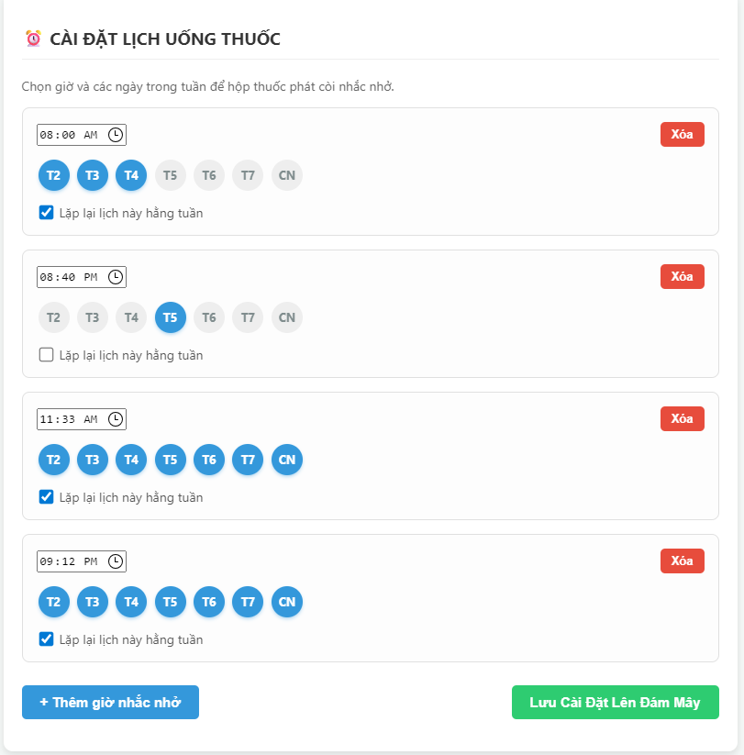
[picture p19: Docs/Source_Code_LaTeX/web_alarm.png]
     
    \caption{Phân hệ cài đặt phác đồ uống thuốc trực quan trên nền tảng Web}
    \label{fig:web_alarm}
\end{figure}

\subsubsection{Thiết kế Tương thích đa nền tảng và Tối ưu hóa truyền tải}
Để đảm bảo tính khả dụng trên đa dạng thiết bị đầu cuối từ máy tính cá nhân, máy tính bảng đến điện thoại di động, giao diện quản trị được xây dựng tuân thủ tiêu chuẩn thiết kế đáp ứng linh hoạt. Bằng việc áp dụng các thuộc tính dàn trang hiện đại của ngôn ngữ định dạng kiểu tĩnh, các khối thông tin thống kê tổng quan (Hôm nay, Tuần này, Tháng này) tự động sắp xếp dàn ngang trên màn hình lớn và tự động chuyển sang cấu trúc xếp chồng dọc khi kích thước khung nhìn thu hẹp, giúp nội dung không bị vỡ bố cục.

\begin{figure}[H]
    \centering
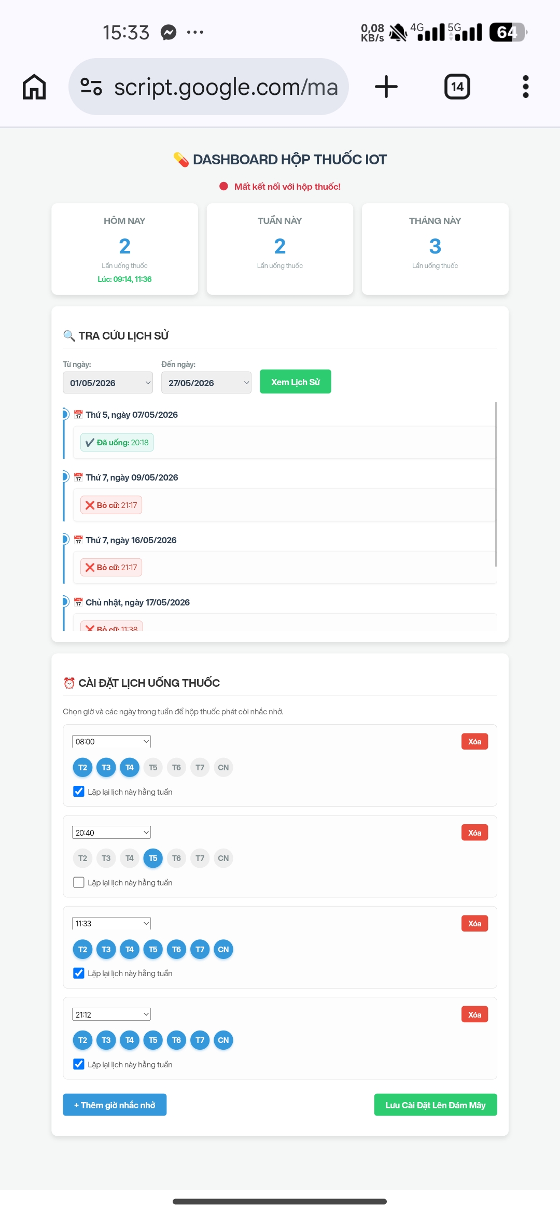
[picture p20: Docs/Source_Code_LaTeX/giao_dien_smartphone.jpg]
     
    \caption{Giao diện hiển thị thực tế của trang quản trị tự động tối ưu hóa và xếp chồng cấu trúc dọc trên màn hình điện thoại di động.}
    \label{fig:giao_dien_smartphone}
\end{figure}

Điểm đột phá của giao diện nằm ở việc ứng dụng kỹ thuật giao tiếp bất đồng bộ thông qua giao diện lập trình nội bộ của hệ sinh thái đám mây. Kỹ thuật này cho phép trang web trao đổi dữ liệu ngầm với máy chủ để cập nhật liên tục trạng thái hoạt động của thiết bị (Nhịp tim) hoặc tải bảng lịch sử uống thuốc mà không cần làm mới lại toàn bộ trang web. Kết quả truy vấn được luân chuyển và cập nhật trực tiếp vào cấu trúc phân cấp phần tử của giao diện, mang lại trải nghiệm tương tác mượt mà và tiết kiệm tối đa băng thông mạng.

\begin{figure}[H]
    \centering
    % Cắt riêng khu vực có cái chấm màu xanh lá cây "Thiết bị đang hoạt động" lưu thành file web_status.png
     
    \caption{Cơ chế cập nhật trạng thái kết nối thiết bị bất đồng bộ theo thời gian thực}
    \label{fig:web_status}
\end{figure}

\subsubsection{Cơ chế bảo mật và Phân quyền truy cập}
Hệ thống thông tin y tế cá nhân đòi hỏi tiêu chuẩn bảo mật nghiêm ngặt nhằm bảo vệ tính riêng tư của người bệnh. Thay vì phải tự xây dựng các cơ chế mã hóa và quản lý phiên đăng nhập phức tạp, dễ phát sinh lỗ hổng bảo mật, đề tài tận dụng tối đa kiến trúc an ninh lớp ứng dụng của hệ sinh thái đám mây quản lý.

Trang web quản trị được triển khai dưới dạng một ứng dụng web nội bộ và kế thừa trực tiếp giao thức xác thực danh tính hai lớp. Quyền truy cập vào bảng điều khiển được kiểm soát chặt chẽ thông qua danh sách chia sẻ của tệp cơ sở dữ liệu. Cụ thể, chỉ những tài khoản thư điện tử được cấp quyền biên tập mới có khả năng truy xuất giao diện và can thiệp vào phác đồ điều trị. Mọi truy cập nặc danh hoặc từ các tài khoản không nằm trong danh sách trắng đều bị máy chủ từ chối phục vụ từ vòng ngoài, ngăn chặn hoàn toàn nguy cơ rò rỉ dữ liệu hoặc tấn công từ chối dịch vụ vào hệ thống.

\newpage
\begin{center}
    \section{KẾT QUẢ THỰC HIỆN}
\end{center}
%Nội dung chương 5

Sau thời gian nghiên cứu, thi công và lập trình, hệ thống "Hộp thuốc thông minh" đã được hoàn thiện. Để đánh giá tính khả thi và độ tin cậy của sản phẩm, hệ thống được đưa vào vận hành thực nghiệm thông qua các bài đo lường hiệu năng và các trường hợp kiểm thử khắt khe.

\subsection{Kết quả thi công phần cứng}
Quá trình thi công phần cứng được thực hiện tuần tự qua các giai đoạn: từ thử nghiệm kiểm chứng thuật toán trên testboard, thi công khối năng lượng, gia công mạch in thủ công cho đến khâu lắp ráp và cố định cơ khí. Kết quả cụ thể ở từng giai đoạn đều đáp ứng tốt các chỉ tiêu kỹ thuật đã đề ra.

\subsubsection{Kết quả thử nghiệm nguyên lý trên Testboard}
Trước khi tiến hành làm mạch in, toàn bộ linh kiện được lắp ráp thử nghiệm trên Testboard để kiểm chứng sơ đồ nguyên lý và sự tương thích của giao thức truyền thông. Kết quả cho thấy vi điều khiển ESP32 giao tiếp thành công với cả màn hình OLED và module đồng hồ DS3231 thông qua chung một bus I2C. Các lỗi nhiễu tín hiệu vật lý ban đầu đã được phát hiện và xử lý triệt để thông qua thuật toán chống dội phím (Debounce) cho công tắc hành trình.

\begin{figure}[H]
    \centering
     % Bạn chèn ảnh chụp mạch cắm testboard vào đây
    \caption{Kết quả chạy thử nghiệm kiểm chứng nguyên lý và giao tiếp I2C trên Testboard}
    \label{fig:ket_qua_testboard}
\end{figure}

\subsubsection{Kết quả thi công mạch nguồn và hệ thống pin Li-Ion}
Hệ thống cấp nguồn di động đã được thi công hoàn thiện và hoạt động ổn định. Thay vì sử dụng các loại pin Polymer giá rẻ, đồ án đã tận dụng thành công cell pin Lithium-Ion tái chế từ điện thoại cũ (dung lượng $\sim 2000$ mAh), mang lại dòng xả cực kỳ ổn định và độ tin cậy hóa học cao.
\begin{itemize}
    \item \textbf{Mạch sạc và nâng áp:} Module J5019 hoạt động trơn tru, nạp tốt cho pin Li-Ion và kích điện áp lên mức 5V ổn định cấp cho hệ thống. Tụ hóa $100\mu F$ được bổ sung tại ngõ vào giúp dập hoàn toàn các xung sụt áp khi ESP32 bật sóng Wi-Fi.
    \item \textbf{Khối đo lường năng lượng:} Cầu phân áp gồm hai điện trở $100k\Omega$ mắc nối tiếp hoạt động chính xác. Điện áp pin được chia đôi và đưa vào chân D33 của bộ ADC1 trên ESP32. Kết quả đối chiếu với đồng hồ VOM cho thấy mạch đọc dữ liệu analog rất tuyến tính, sai số ở mức chấp nhận được và không gây hao hụt dung lượng pin nhờ nội trở cầu phân áp lớn.
\end{itemize}

\begin{figure}[H]
    \centering
     % Bạn chèn ảnh cụm mạch J5019 và cục pin vào đây
    \caption{Khối năng lượng sử dụng pin Li-Ion tái chế và module tích hợp J5019}
    \label{fig:ket_qua_nguon_pin}
\end{figure}

\subsubsection{Kết quả gia công mạch in (PCB) thủ công}
Mạch điện được gia công hoàn toàn bằng phương pháp ủi nhiệt và ăn mòn hóa học trong điều kiện phòng thí nghiệm. Nhờ việc thiết lập quy tắc thiết kế đi dây với độ rộng lớn (30-35 mil) và loại bỏ các góc gấp khúc 90 độ, kết quả phôi đồng sau khi ăn mòn đạt chất lượng rất tốt.
\begin{itemize}
    \item Các đường dẫn tín hiệu sắc nét, không xuất hiện tình trạng rỗ mạch hay đứt gãy đứt ngầm. 
    \item Các lỗi mối hàn ban đầu tại các chân rào cắm do diện tích tản nhiệt của bề mặt đồng quá lớn đã được khắc phục hoàn toàn bằng phương pháp gia nhiệt lại kết hợp nhựa thông lỏng, đảm bảo sự tiếp xúc điện tiêu chuẩn cho các module ngoại vi.
\end{itemize}

\begin{figure}[H]
    \centering
     % Bạn chèn ảnh chụp bo mạch in vừa ủi/hàn xong (chưa lắp vào hộp) vào đây
    \caption{Bo mạch in một lớp hoàn thiện sau quá trình ăn mòn và hàn linh kiện}
    \label{fig:ket_qua_pcb}
\end{figure}

\subsubsection{Kết quả lắp ráp hoàn thiện sản phẩm}
Toàn bộ hệ thống mạch điều khiển, cơ cấu nguồn và các linh kiện ngoại vi được định vị và cố định chắc chắn vào bên trong không gian giới hạn của vỏ hộp cơ khí. Thiết kế đảm bảo sự liền mạch, thẩm mỹ và an toàn điện khi người dùng trực tiếp thao tác.
\begin{itemize}
    \item Màn hình OLED hiển thị rõ nét thời gian thực và ghi chú cữ thuốc với độ tương phản cao, hoạt động mượt mà với cơ chế giảm độ sáng (Dimming) tiết kiệm năng lượng.
    \item Còi báo động (Active Buzzer) phát tín hiệu âm thanh to, dứt khoát, đủ để thu hút sự chú ý của bệnh nhân lớn tuổi khi đến cữ.
    \item Công tắc hành trình phản hồi trạng thái cơ học vật lý chính xác. Các tác động đóng/mở nắp lập tức kích hoạt luồng cảnh báo ưu tiên trên màn hình mà không xảy ra bất kỳ sự cố treo hệ thống hay gửi sai lệch dữ liệu nào.
\end{itemize}

\begin{figure}[H]
    \centering
     % Chèn ảnh mặt trước (thấy màn hình)
    \caption{Hình ảnh thực tế mặt trước của Hộp thuốc thông minh sau khi lắp ráp hoàn thiện}
    \label{fig:mo_hinh_mat_truoc}
\end{figure}

\begin{figure}[H]
    \centering
     % Chèn ảnh mặt sau/bên trong/cơ khí
    \caption{Góc nhìn mặt sau thể hiện cấu trúc bố trí ngoại vi và hệ thống nắp hộp}
    \label{fig:mo_hinh_mat_sau}
\end{figure}

\subsection{Đánh giá thời gian đáp ứng và độ trễ truyền thông}
Một trong những thách thức lớn nhất của kiến trúc máy chủ phi tập trung là độ trễ khởi động ban đầu. Qua quá trình đo đạc thực tế bằng hàm đếm thời gian trên vi điều khiển, kết quả thời gian đáp ứng của hệ thống ghi nhận như sau:
\begin{itemize}
    \item \textbf{Thời gian thiết lập kết nối:} Mất trung bình $5.5 - 7.0$ giây để vi điều khiển thức dậy và hoàn tất quá trình bắt tay bảo mật mạng với máy chủ.
    \item \textbf{Độ trễ đẩy dữ liệu lên máy chủ:} Thời gian từ lúc mở nắp hộp đến khi dữ liệu được ghi nhận thành công trên bảng tính dao động từ $1.5- 3.5$ giây.
    \item \textbf{Độ trễ cảnh báo qua tin nhắn:} Tin nhắn đẩy về điện thoại người nhà gần như tức thời (dưới $5.0$ giây) kể từ khi hệ thống phát hiện vi phạm thời gian uống thuốc.
\end{itemize}
Nhìn chung, độ trễ tổng thể của hệ thống nằm trong ngưỡng dưới 10 giây, tuy không thực sự quá nhanh nhưng hoàn toàn đáp ứng được yêu cầu về thời gian thực cho một ứng dụng cảnh báo y tế.

\subsection{Kiểm thử các trường hợp vận hành thực tế}
Để đảm bảo hệ thống không bị lỗi xử lý logic trong quá trình sử dụng dài hạn, các trường hợp ngoại lệ cũng như thường xuyên đã được giả lập và kiểm thử thực tế.

\textbf{Trường hợp 1: Khởi tạo và cấu hình mạng lưới qua Cổng thông tin nội bộ (Captive Portal)}
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

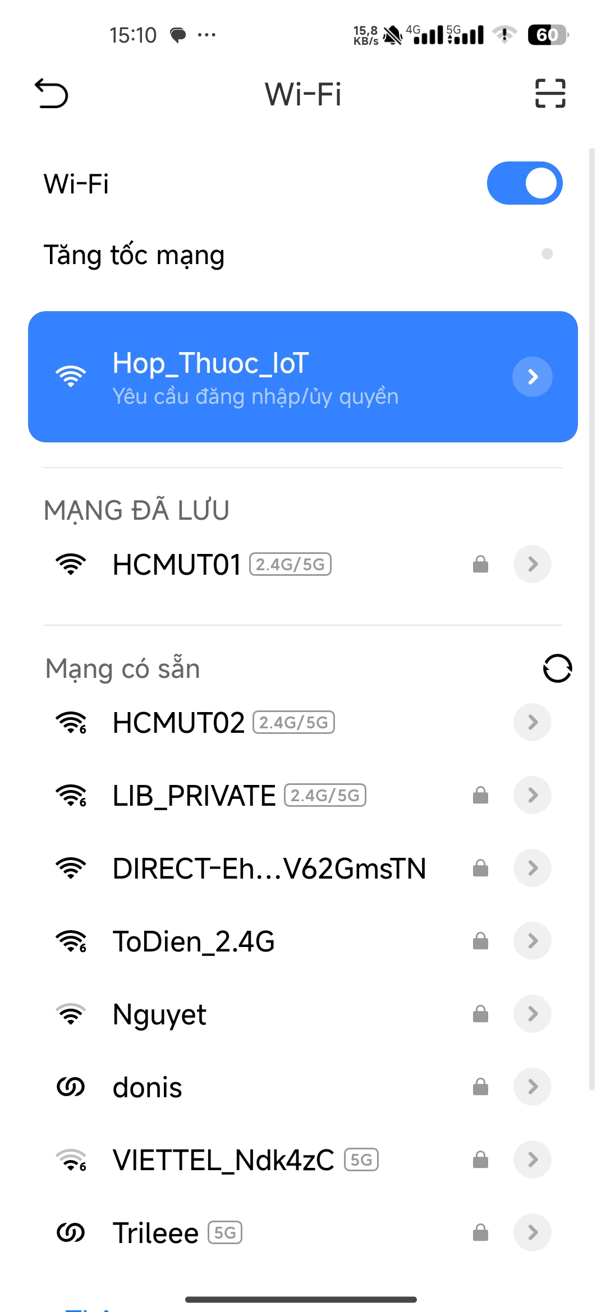
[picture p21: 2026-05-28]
Docs/Source_Code_LaTeX/wifi_scan.jpg

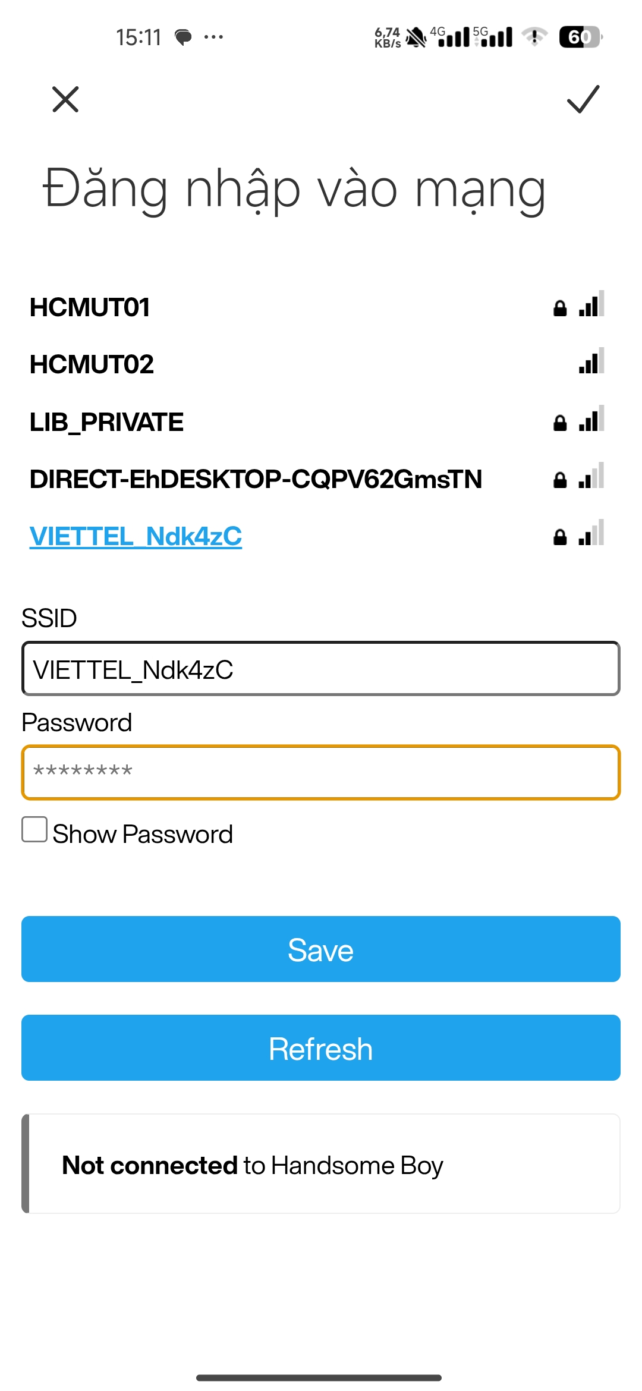
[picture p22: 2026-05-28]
Docs/Source_Code_LaTeX/wifi_manager.jpg

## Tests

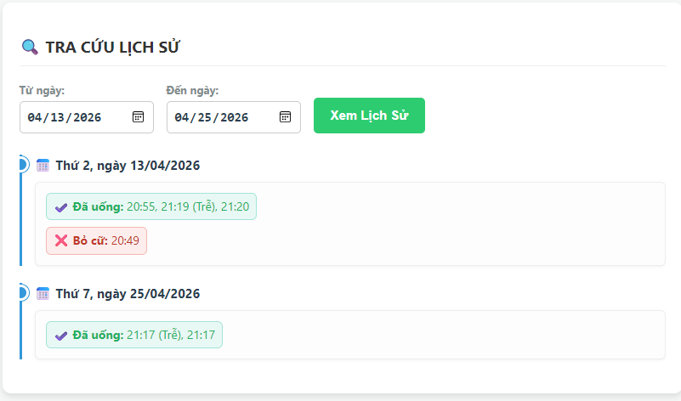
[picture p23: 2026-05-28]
Docs/Source_Code_LaTeX/test_uong_tre_web.png

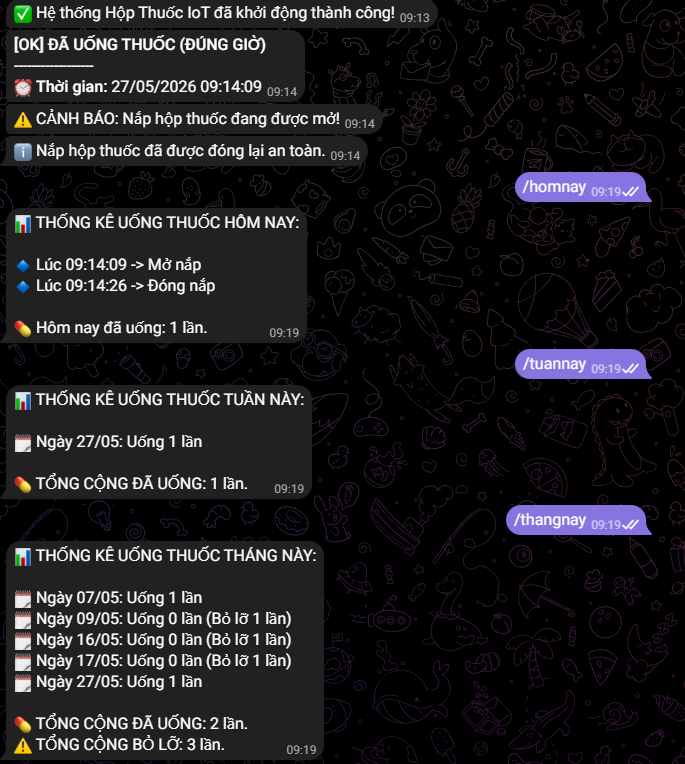
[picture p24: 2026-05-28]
Docs/Source_Code_LaTeX/test_truy_van_tele.png

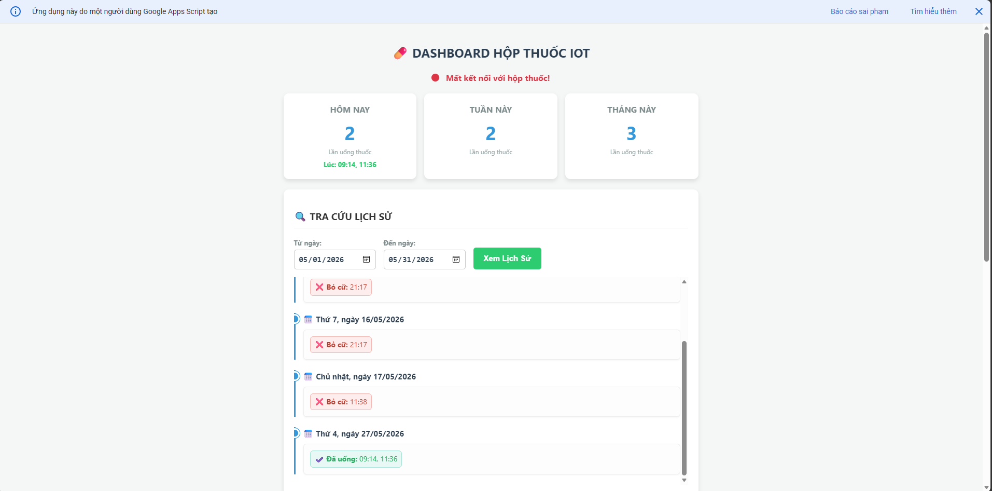
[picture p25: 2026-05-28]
Docs/Source_Code_LaTeX/test_uong_dung_gio2.png

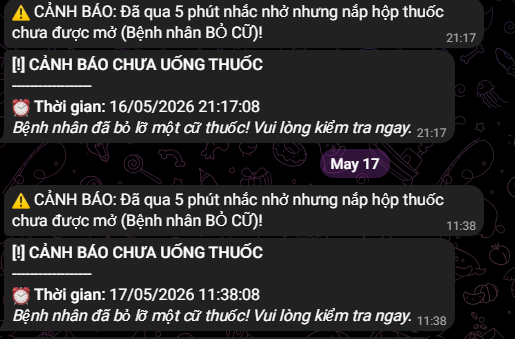
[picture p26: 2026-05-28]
Docs/Source_Code_LaTeX/test_bo_thuoc_tele.png

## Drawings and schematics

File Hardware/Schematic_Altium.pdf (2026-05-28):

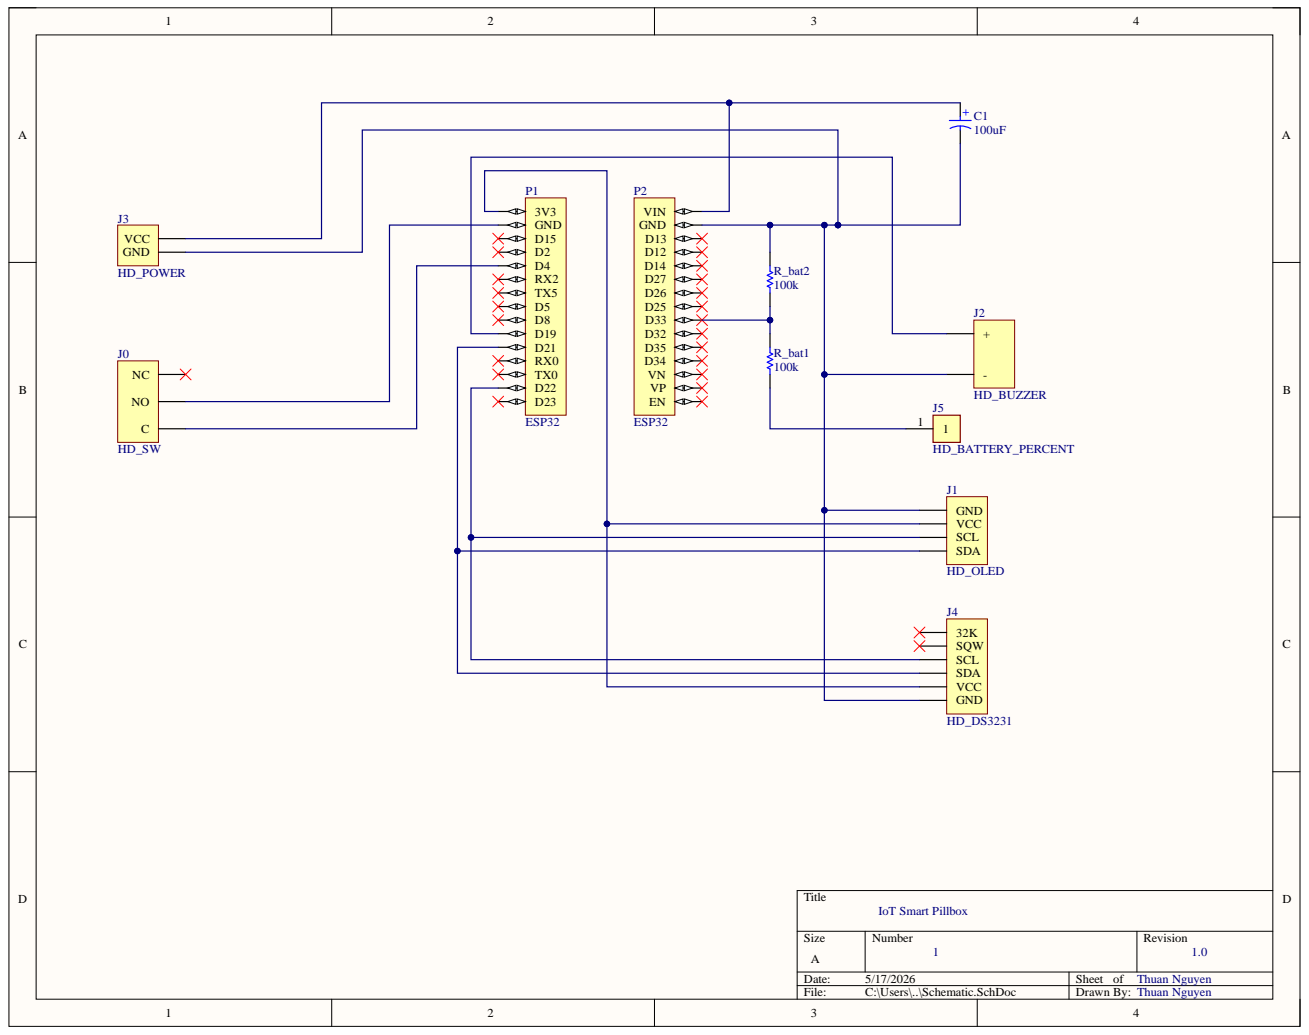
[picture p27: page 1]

RX 2 T X 5 D 5 D 8 D19 D21 | VIN GND D13 D12 D14 D27 D26 D25 D33 D32 D35 D34 VNVP EN P2ESP32

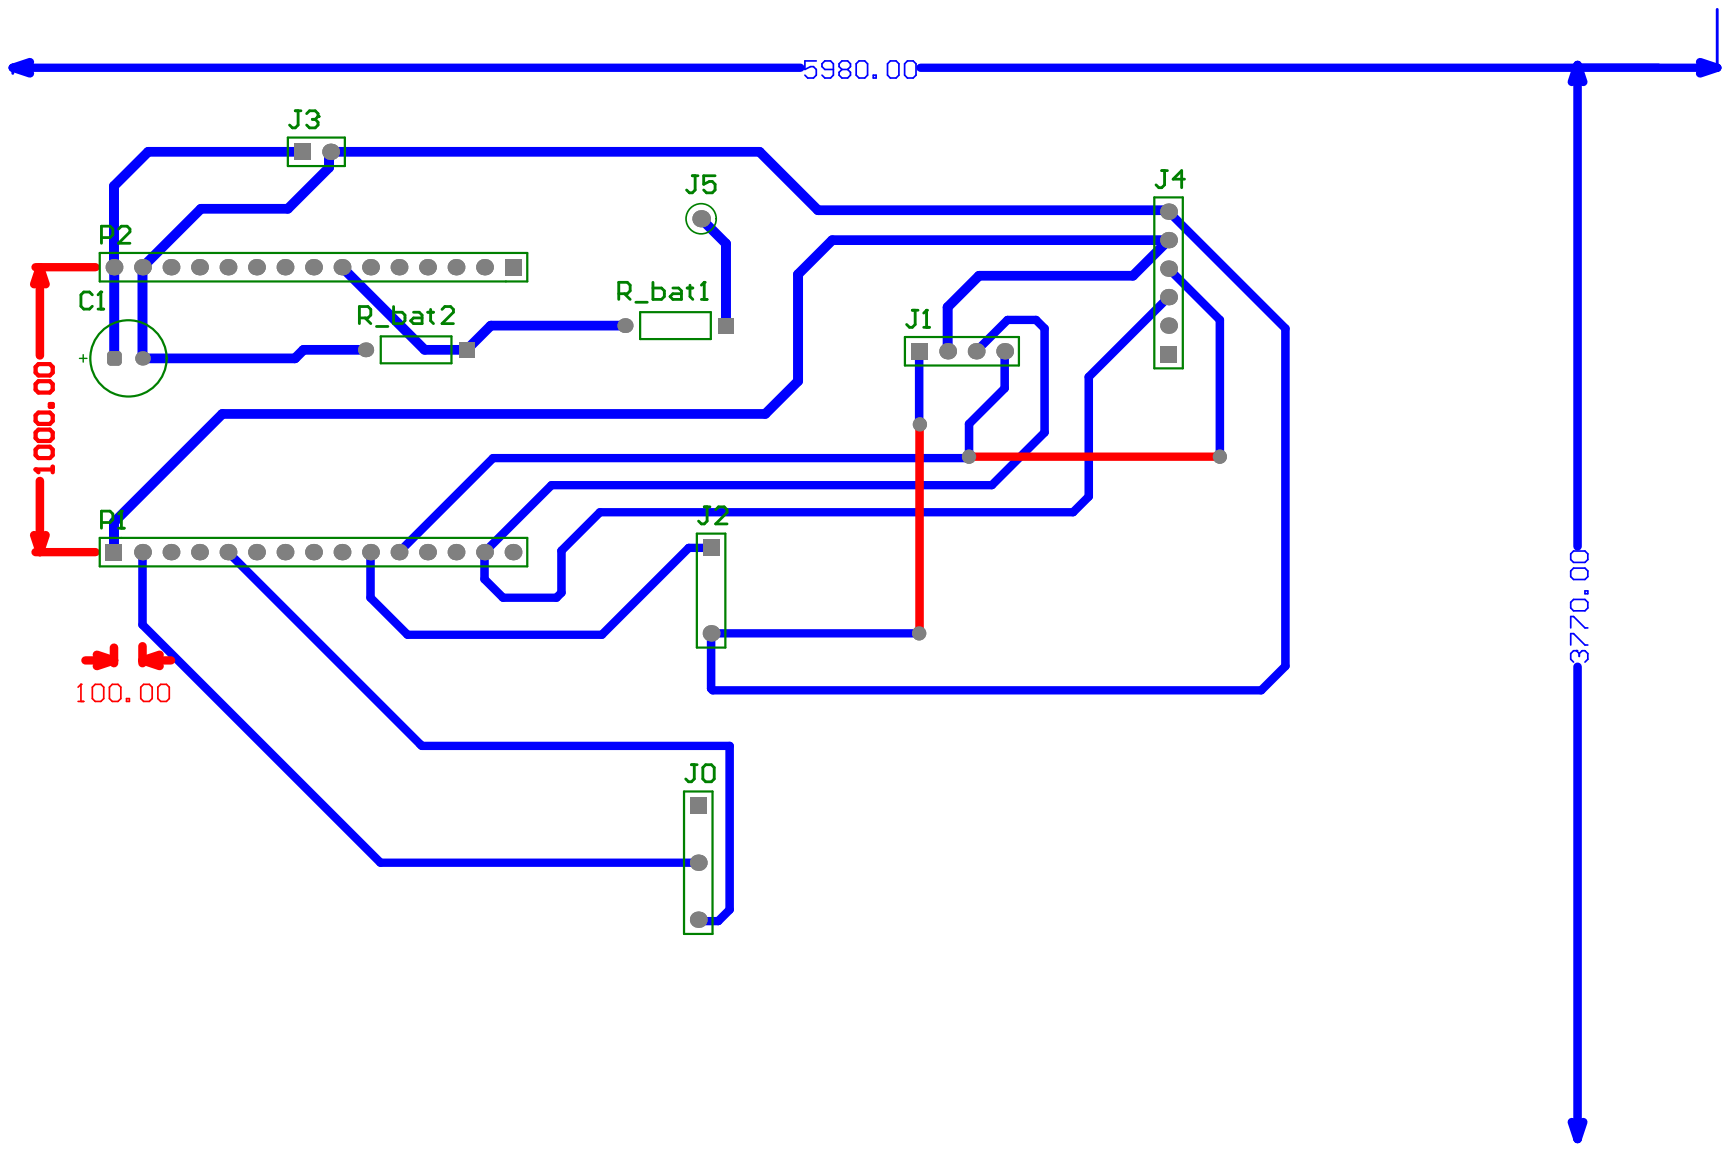
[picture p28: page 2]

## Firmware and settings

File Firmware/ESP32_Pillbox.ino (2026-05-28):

#include <WiFi.h>
#include <WiFiManager.h>
#include <HTTPClient.h>
#include <WiFiClientSecure.h>
#include <Wire.h>
#include <Adafruit_GFX.h>
#include <Adafruit_SSD1306.h>
#include "time.h"
#include "RTClib.h"
#include <Preferences.h>

RTC_DS3231 rtc;
DateTime globalNow;
Preferences preferences;

// --- 1. ĐỊNH NGHĨA CHÂN VÀ THÔNG TIN CLOUD ---
#define SWITCH_PIN 4 
#define BUZZER_PIN 19 
String botToken = "8729962677:AAGrT5_69f5CqL8aJl88RomJfY0KPr3c-cs"; 
String chatId = "1922974253"; 
String googleScriptUrl = "https://script.google.com/macros/s/AKfycbyWvpzWuLJ_vV84Uc3rvG5cOGRKCblE85hYOkTFurOL_UT4WP3MSYsnFkm6WfHzJIYH/exec"; 

// --- 2. CẤU HÌNH OLED ---
#define SCREEN_WIDTH 128
#define SCREEN_HEIGHT 64
Adafruit_SSD1306 display(SCREEN_WIDTH, SCREEN_HEIGHT, &Wire, -1);
String currentAction = "He thong san sang"; 

// --- 3. BIẾN DEBOUNCE CÔNG TẮC ---
int lastSwitchState = LOW;
int currentSwitchState = LOW;
unsigned long lastDebounceTime = 0;
unsigned long debounceDelay = 100; 

// --- 4. BIẾN QUẢN LÝ BÁO THỨC & THỜI GIAN ---
struct Alarm {
  int h;
  int m;
  String days;
  bool rungToday; 
};
#define MAX_ALARMS 10
Alarm myAlarms[MAX_ALARMS];
int numAlarms = 0;
unsigned long lastAlarmEndTime = 0; 
bool inLateWindow = false;
bool isAlarmRinging = false;
unsigned long alarmStartTime = 0; 
unsigned long lastSyncTime = 0;
const unsigned long SYNC_INTERVAL = 6 * 3600000; 
unsigned long lastActivityTime = 0;
unsigned long lastPingTime = 0;
const unsigned long PING_INTERVAL = 2 * 60000; // 2 phút (tính bằng mili-giây)

// --- KHAI BÁO CHÂN PIN ---
const int BATTERY_PIN = 33; // Cấu hình đọc áp pin ở chân D33

// --- BIẾN TOÀN CỤC CHO GIAO DIỆN OLED ---
String gioUongThuocKeTiep = "--:--"; 
String dongThongBao = "";

// CÁC BIẾN CHO HIỆU ỨNG THÔNG BÁO 10 GIÂY
unsigned long notificationStartTime = 0; 
bool isShowingNotification = false;      
String tempNotification = "";

// --- BIẾN QUẢN LÝ ĐỘ SÁNG OLED (AOD) ---
unsigned long thoiGianSangManHinh = 0; 
bool isDimmed = false; // Cờ theo dõi trạng thái màn hình

// --- HÀM 1: CẬP NHẬT GIAO DIỆN OLED ---
void capNhatOLED() {
  display.clearDisplay();
  DateTime now = rtc.now(); 
  int phanTramPin = docPhanTramPin(); 

  display.setTextWrap(false); 

  // DÒNG 1: NGÀY THÁNG & PIN
  display.setTextSize(1);
  display.setTextColor(SSD1306_WHITE);
  display.setCursor(0, 0);
  if(now.day() < 10) display.print('0');
  display.print(now.day(), DEC); display.print('/');
  if(now.month() < 10) display.print('0');
  display.print(now.month(), DEC); display.print('/');
  display.print(now.year(), DEC);

  display.setCursor(102, 0);
  display.print(phanTramPin); display.print("%");

  // DÒNG 2: GIỜ & PHÚT 
  display.setTextSize(2);
  display.setCursor(34, 18); 
  if(now.hour() < 10) display.print('0');
  display.print(now.hour(), DEC); display.print(':');
  if(now.minute() < 10) display.print('0');
  display.print(now.minute(), DEC);

  // DÒNG 3: DÒNG THÔNG BÁO LINH HOẠT
  display.setTextSize(1);
  display.setCursor(0, 46); // Kéo lên vị trí 46 để đủ không gian cho 2 dòng chữ
  display.print(dongThongBao); 

  display.display();
}

// --- HÀM 2: TÌM LỊCH UỐNG THUỐC TIẾP THEO ĐỂ HIỂN THỊ (ĐÃ FIX LOGIC THỨ) ---
String timBaoThucTiepTheo() {
  if (numAlarms == 0) return "Chua cai dat lich.";
  
  DateTime now = rtc.now();
  int currMins = now.hour() * 60 + now.minute();
  int currWday = now.dayOfTheWeek(); // 0=CN, 1=T2, 2=T3...

  int minMinsFromNow = 999999;
  int nextH = -1;
  int nextM = -1;
  int nextDayDiff = -1;

  for(int i=0; i<numAlarms; i++) {
    int alarmMins = myAlarms[i].h * 60 + myAlarms[i].m;
    
    // Rà soát cả 7 ngày trong tuần xem ngày nào được Web tick chọn
    for(int d=0; d<7; d++) {
      if (myAlarms[i].days.indexOf(String(d)) != -1) { 
        
        int daysDiff = (d - currWday + 7) % 7;
        int minsFromNow = daysDiff * 24 * 60 + (alarmMins - currMins);
        
        // Nếu báo thức thuộc hôm nay nhưng giờ đã qua -> Tính cộng thêm 7 ngày cho tuần sau
        if (minsFromNow <= 0) {
          minsFromNow += 7 * 24 * 60;
        }

        // Tìm ra cột mốc gần nhất với thời điểm hiện tại
        if (minsFromNow < minMinsFromNow) {
          minMinsFromNow = minsFromNow;
          nextH = myAlarms[i].h;
          nextM = myAlarms[i].m;
          
          if (daysDiff == 0 && alarmMins <= currMins) {
             nextDayDiff = 7; // Lịch của tuần sau
          } else {
             nextDayDiff = daysDiff;
          }
        }
      }
    }
  }

  if (nextH == -1) return "Chua chon thu!";

  char buf[30];
  if (nextDayDiff == 0) {
    sprintf(buf, "%02d:%02d (Hom nay)", nextH, nextM);
  } else if (nextDayDiff == 1) {
    sprintf(buf, "%02d:%02d (Ngay mai)", nextH, nextM);
  } else {
    int targetWday = (currWday + nextDayDiff) % 7;
    String dayName = (targetWday == 0) ? "CN" : "T" + String(targetWday + 1);
    sprintf(buf, "%02d:%02d (%s)", nextH, nextM, dayName.c_str());
  }
  
  return "Lich tiep theo:\n" + String(buf);
}

// --- HÀM 3: TẢI BÁO THỨC TỪ GOOGLE SHEETS ---
void taiBaoThucTuGoogle() {
  if (WiFi.status() == WL_CONNECTED) {
    WiFiClientSecure client; client.setInsecure(); HTTPClient http;
    Serial.println("\nĐang tải lịch từ Web...");
    http.begin(client, googleScriptUrl + "?action=get_alarms");
    http.setFollowRedirects(HTTPC_STRICT_FOLLOW_REDIRECTS);
    
    int httpCode = http.GET();
    if (httpCode == 200 || httpCode == 302) {
      String payload = http.getString();
      numAlarms = 0; int startIdx = 0;
      
      while(startIdx < payload.length() && numAlarms < MAX_ALARMS) {
         int commaIdx = payload.indexOf(',', startIdx);
         if(commaIdx == -1) commaIdx = payload.length();
         String alarmStr = payload.substring(startIdx, commaIdx); 
         int pipe1 = alarmStr.indexOf('|'); int pipe2 = alarmStr.indexOf('|', pipe1 + 1);
         if(pipe1 != -1 && pipe2 != -1) {
             String t = alarmStr.substring(0, pipe1); 
             myAlarms[numAlarms].h = t.substring(0,2).toInt();
             myAlarms[numAlarms].m = t.substring(3,5).toInt();
             myAlarms[numAlarms].days = alarmStr.substring(pipe1+1, pipe2); 
             myAlarms[numAlarms].rungToday = false;
             numAlarms++;
         }
         startIdx = commaIdx + 1;
      }
      
      //LƯU LỊCH VÀO FLASH CHO CHẾ ĐỘ OFFLINE//
      preferences.begin("Pillbox", false);
      preferences.putInt("numAlarms", numAlarms);
      for(int i=0; i<numAlarms; i++) {
        preferences.putInt(("h" + String(i)).c_str(), myAlarms[i].h);
        preferences.putInt(("m" + String(i)).c_str(), myAlarms[i].m);
        preferences.putString(("d" + String(i)).c_str(), myAlarms[i].days);
      }
      preferences.end();
      Serial.println("Đã đồng bộ và lưu lịch Offline!");
    }
    http.end();
  }
}

// --- HÀM 4: KIỂM TRA ĐẾN GIỜ KÊU ---
void kiemTraBaoThuc() {
  if (isAlarmRinging) return; 

  //DateTime now = rtc.now(); // Bỏ luôn việc kiểm tra có mạng hay không

  for(int i=0; i < numAlarms; i++) {
    if(globalNow.hour() == myAlarms[i].h && globalNow.minute() == myAlarms[i].m) {
      String currentDay = String(globalNow.dayOfTheWeek());
      if(myAlarms[i].days.indexOf(currentDay) != -1) {
         if(!myAlarms[i].rungToday) {
            isAlarmRinging = true; 
            alarmStartTime = millis(); 
            myAlarms[i].rungToday = true; 
            currentAction = ">>> DEN GIO UONG THUOC <<<";
            Serial.println("KÍCH HOẠT BÁO THỨC!");
         }
      }
    } else {
      myAlarms[i].rungToday = false; 
    }
  }
}

void setup() {
  // --- HẠ XUNG NHỊP CPU XUỐNG 80MHz ĐỂ TIẾT KIỆM PIN ---
  setCpuFrequencyMhz(80);
  Serial.begin(115200);
  pinMode(SWITCH_PIN, INPUT_PULLUP); 
  pinMode(BUZZER_PIN, OUTPUT); digitalWrite(BUZZER_PIN, LOW); 

  if(!display.begin(SSD1306_SWITCHCAPVCC, 0x3C)) {
    Serial.println(F("Lỗi: Không tìm thấy OLED")); for(;;); 
  }
  
  display.clearDisplay(); display.setTextSize(1); display.setTextColor(WHITE);
  display.setCursor(0, 20); display.println("Dang ket noi WiFi..."); display.display();

  // 1. KHỞI TẠO RTC
  if (!rtc.begin()) {
    Serial.println("Lỗi: Không tìm thấy module DS3231");
  }
  
  // SỬA LỖI LOGIC: Cảnh báo nếu Pin RTC có vấn đề
  if (rtc.lostPower()) {
    Serial.println("CẢNH BÁO: Mất nguồn RTC! Kiểm tra ngay pin CR2032.");
    
    // Hiển thị trực tiếp ra màn hình OLED để bắt bệnh
    display.clearDisplay();
    display.setCursor(0, 10);
    display.println("!! CANH BAO !!");
    display.println("Pin DS3231 bi long");
    display.println("Hoac lap nguoc cuc!");
    display.display();
    delay(4000); // Dừng 4 giây để bạn kịp đọc cảnh báo
    
    // Tạm lấy giờ nạp code để mạch không bị kẹt ở năm 1970
    rtc.adjust(DateTime(F(__DATE__), F(__TIME__))); 
  }

  // 2. NẠP DỮ LIỆU OFFLINE TỪ FLASH LÊN RAM
  preferences.begin("Pillbox", true); // true = Read Only
  numAlarms = preferences.getInt("numAlarms", 0);
  for(int i=0; i<numAlarms; i++) {
    myAlarms[i].h = preferences.getInt(("h" + String(i)).c_str(), 0);
    myAlarms[i].m = preferences.getInt(("m" + String(i)).c_str(), 0);
    myAlarms[i].days = preferences.getString(("d" + String(i)).c_str(), "");
    myAlarms[i].rungToday = false;
  }
  preferences.end();
  Serial.printf("Đã nạp %d lịch báo thức Offline.\n", numAlarms);

  // 3. THỬ KẾT NỐI WIFI
  WiFiManager wm;
  wm.setConfigPortalTimeout(60); 
  bool res = wm.autoConnect("Hop_Thuoc_IoT"); 
  
  if(!res) {
    // KHÔNG CÓ MẠNG -> CHẠY OFFLINE
    currentAction = "Che do Offline";
    Serial.println("Không kết nối được WiFi. Chạy bằng dữ liệu nội bộ!");
  } else {
    // CÓ MẠNG -> ĐỒNG BỘ GIỜ VÀ LỊCH
    currentAction = "Da ket noi WiFi!";
    WiFi.setTxPower(WIFI_POWER_8_5dBm); // Giảm công suất sóng Wi-Fi để chống sập nguồn
    capNhatOLED();
    
    // NÂNG CẤP LỖI NTP: Sử dụng vòng lặp chờ an toàn
    delay(2000); 
    configTime(7 * 3600, 0, "time.google.com", "time.windows.com", "pool.ntp.org");
    
    struct tm timeinfo;
    Serial.print("Đang dong bo NTP...");
    
    int retry = 0;
    while (!getLocalTime(&timeinfo, 1000) && retry < 10) { 
      Serial.print(".");
      retry++;
    }
    
    if (retry < 10) { 
      // Ép kiểu chuẩn cấu trúc DateTime của RTClib
      rtc.adjust(DateTime(timeinfo.tm_year + 1900, timeinfo.tm_mon + 1, timeinfo.tm_mday, timeinfo.tm_hour, timeinfo.tm_min, timeinfo.tm_sec));
      Serial.println("\n[OK] Đã nạp lại giờ chuẩn mạng cho DS3231.");
    } else {
      Serial.println("\n[LỖI] Mạng quá yếu, không tải được giờ mạng!");
    }
    
    sendTelegramMessage("✅ Hệ thống Hộp Thuốc IoT đã khởi động thành công!");
    logToGoogleSheets("Ping");
    taiBaoThucTuGoogle();
    lastSyncTime = millis();
  }

  // 4. KẾT THÚC SETUP
  digitalWrite(BUZZER_PIN, HIGH); delay(100); digitalWrite(BUZZER_PIN, LOW);
  currentAction = timBaoThucTiepTheo();
  capNhatOLED();
}

void loop() {
  unsigned long currentMillis = millis();

  // --- 0. GỬI NHỊP TIM (PING) ---
  if (currentMillis - lastPingTime > PING_INTERVAL) {
    if (WiFi.status() == WL_CONNECTED) {
      logToGoogleSheets("Ping");
    }
    lastPingTime = currentMillis;
  }

  // --- 1. QUÉT BÁO THỨC & CẬP NHẬT OLED (Mỗi 1 giây) ---
  static unsigned long lastTimeUpdate = 0;
  static int lastMinute = -1; 
  
  if (currentMillis - lastTimeUpdate > 1000) {
    globalNow = rtc.now();
    kiemTraBaoThuc();
    
    if (!isAlarmRinging && globalNow.minute() != lastMinute) {
      gioUongThuocKeTiep = timBaoThucTiepTheo(); 
      lastMinute = globalNow.minute();
    }

    // LOGIC ƯU TIÊN HIỂN THỊ DÒNG THÔNG BÁO
    if (isAlarmRinging) {
        dongThongBao = ">> DEN GIO UONG! <<";
        thoiGianSangManHinh = currentMillis; 
    } 
    else if (isShowingNotification) {
        if (currentMillis - notificationStartTime <= 10000) {
            dongThongBao = tempNotification;
        } else {
            isShowingNotification = false; 
            dongThongBao = gioUongThuocKeTiep;
        }
    } 
    else {
        dongThongBao = gioUongThuocKeTiep;
    }

    // ======================================================
    // LOGIC TIẾT KIỆM PIN: DEEP DIMMING SAU 30 GIÂY
    // ======================================================
    if (currentMillis - thoiGianSangManHinh <= 30000) {
        // --- CHẾ ĐỘ SÁNG BÌNH THƯỜNG ---
        if (isDimmed) {
            // 1. Phục hồi thời gian nạp mồi (Mặc định của thư viện là 0xF1)
            display.ssd1306_command(SSD1306_SETPRECHARGE);
            display.ssd1306_command(0xF1); 
            // 2. Phục hồi điện áp nền VCOMH (Mặc định là 0x40)
            display.ssd1306_command(SSD1306_SETVCOMDETECT);
            display.ssd1306_command(0x40);
            // 3. Phục hồi độ sáng tối đa
            display.ssd1306_command(SSD1306_SETCONTRAST);
            display.ssd1306_command(255); 
            
            isDimmed = false;
        }
    } else {
        // --- CHẾ ĐỘ NGỦ MỜ (DEEP DIMMING) ---
        if (!isDimmed) {
            // 1. Cắt giảm tối đa thời gian nạp mồi (Xuống mức 0x22)
            display.ssd1306_command(SSD1306_SETPRECHARGE);
            display.ssd1306_command(0x22); 
            // 2. Ép điện áp nền VCOMH xuống mức thấp nhất
            display.ssd1306_command(SSD1306_SETVCOMDETECT);
            display.ssd1306_command(0x00);
            // 3. Hạ Contrast về 0 (Mức thấp tuyệt đối)
            display.ssd1306_command(SSD1306_SETCONTRAST);
            display.ssd1306_command(0); 
            
            isDimmed = true;
        }
    }

    capNhatOLED();
    lastTimeUpdate = currentMillis;
  }

  // --- 2. LOGIC ĐỔ CHUÔNG BÁO THỨC & XỬ LÝ BỎ CỮ ---
  if (isAlarmRinging) {
     lastActivityTime = millis();
     unsigned long elapsed = millis() - alarmStartTime;
     
     if (elapsed >= 300000UL) { 
        isAlarmRinging = false;
        digitalWrite(BUZZER_PIN, LOW); 
        
        // LUÔN GỬI SHEETS TRƯỚC VÀ NGHỈ 1S
        logToGoogleSheets("Bo_Thuoc"); 
        delay(1000);
        sendTelegramMessage("⚠️ CẢNH BÁO: Đã qua 5 phút nhắc nhở nhưng nắp hộp chưa mở (BỎ CỮ)!");
        
        gioUongThuocKeTiep = timBaoThucTiepTheo();
        lastAlarmEndTime = millis(); 
        inLateWindow = true; 
     } else {
        unsigned long cyclePos = elapsed % 40000UL;
        if (cyclePos < 10000UL) {
            if ((millis() % 1000) < 500) digitalWrite(BUZZER_PIN, HIGH);
            else digitalWrite(BUZZER_PIN, LOW);
        } else {
            digitalWrite(BUZZER_PIN, LOW);
        }
     }
  }

  // --- 3. ĐỌC CÔNG TẮC HÀNH TRÌNH (Kèm Uống trễ & Ghi Log) ---
  int reading = digitalRead(SWITCH_PIN);
  if (reading != lastSwitchState) lastDebounceTime = currentMillis; 

  if ((currentMillis - lastDebounceTime) > debounceDelay) {
    if (reading != currentSwitchState) {
      currentSwitchState = reading;
      lastActivityTime = millis(); 
      thoiGianSangManHinh = millis();
      
      if (currentSwitchState == HIGH) { // ===== TRẠNG THÁI: MỞ NẮP =====
        tempNotification = ">> HOP DANG MO <<";
        isShowingNotification = true;
        notificationStartTime = millis(); 

        if (inLateWindow) {
          if (millis() - lastAlarmEndTime <= 1500000UL) { 
            // GỬI SHEETS TRƯỚC, NGHỈ 1S, RỒI GỬI TELEGRAM
            logToGoogleSheets("Uong_Tre");
            delay(1000);
            sendTelegramMessage("✅ Cập nhật: Bệnh nhân đã uống thuốc bù (Uống trễ)!");
            Serial.println("Ghi nhận: Uống trễ.");
          }
          inLateWindow = false;
        }
        else if (isAlarmRinging) {
           isAlarmRinging = false;
           inLateWindow = false;
           digitalWrite(BUZZER_PIN, LOW);
           Serial.println("Đã tắt báo thức do người dùng mở nắp.");
        }
        
        // Kịch bản C: Log trạng thái Mở nắp chung
        logToGoogleSheets("Mo_Nap");
        delay(1000);
        sendTelegramMessage("⚠️ CẢNH BÁO: Nắp hộp thuốc đang được mở!");
        
      } 
      else { // ===== TRẠNG THÁI: ĐÓNG NẮP =====
        tempNotification = ">> DA DONG NAP <<";
        isShowingNotification = true;
        notificationStartTime = millis(); 

        digitalWrite(BUZZER_PIN, HIGH); delay(100); digitalWrite(BUZZER_PIN, LOW); 
        
        // GỬI SHEETS TRƯỚC, NGHỈ 1S, RỒI GỬI TELEGRAM
        logToGoogleSheets("Dong_Nap");
        delay(1000);
        sendTelegramMessage("ℹ️ Nắp hộp thuốc đã được đóng lại an toàn.");
        
        gioUongThuocKeTiep = timBaoThucTiepTheo();
      }
    }
  }   
  lastSwitchState = reading;
  
  // --- 4. ĐỒNG BỘ LỊCH TỰ ĐỘNG TỪ GOOGLE SHEETS ---
  if (currentMillis - lastSyncTime > SYNC_INTERVAL) {
    taiBaoThucTuGoogle();
    lastSyncTime = currentMillis;
  }
}

void sendTelegramMessage(String message) {
  if (WiFi.status() == WL_CONNECTED) {
    WiFiClientSecure client; client.setInsecure(); HTTPClient http;
    message.replace(" ", "%20");
    http.begin(client, "https://api.telegram.org/bot" + botToken + "/sendMessage?chat_id=" + chatId + "&text=" + message);
    http.GET(); http.end();
  }
} 



void logToGoogleSheets(String action) {
  if (WiFi.status() == WL_CONNECTED) {
    WiFiClientSecure client; client.setInsecure(); HTTPClient http;
    http.begin(client, googleScriptUrl + "?action=" + action);
    http.setFollowRedirects(HTTPC_STRICT_FOLLOW_REDIRECTS);
    
    // Bắt buộc phải lấy mã phản hồi từ Google
    int httpCode = http.GET(); 
    String payload = http.getString(); // THÊM MỚI: Đọc nội dung phản hồi từ Google
    http.end();
    
    if (httpCode > 0) {
      // In thẳng nội dung phản hồi ra màn hình để bắt lỗi
      Serial.println("Đã gửi Cloud: " + action + " - Phản hồi: " + payload);
    } else {
      Serial.println("LỖI GỬI CLOUD: " + action + " (Mã lỗi: " + String(httpCode) + " - " + http.errorToString(httpCode) + ")");
    }
  } else {
    // NẾU MẤT MẠNG -> LƯU VÀO FLASH (OFFLINE QUEUE)
    DateTime now = rtc.now();
    String timeStr = String(now.day()) + "/" + String(now.month()) + "/" + String(now.year()) + " " + 
                     String(now.hour()) + ":" + String(now.minute()) + ":" + String(now.second());
    
    preferences.begin("OfflineData", false);
    int count = preferences.getInt("q_count", 0); 
    preferences.putString(("act" + String(count)).c_str(), action);
    preferences.putString(("time" + String(count)).c_str(), timeStr);
    preferences.putInt("q_count", count + 1); 
    preferences.end();
    
    Serial.println("Rớt mạng! Đã lưu Offline sự kiện: " + action);
  }
}

// --- HÀM ĐỌC VÀ TÍNH TOÁN PHẦN TRĂM PIN ---
int docPhanTramPin() {
  // Lấy giá trị ADC từ chân 34 (Độ phân giải 12-bit: 0 - 4095)
  int adcValue = analogRead(BATTERY_PIN);
  
  // Tính điện áp tại chân ESP32 (V_ADC)
  // ESP32 có điện áp tham chiếu là 3.3V
  float adcVoltage = (adcValue / 4095.0) * 3.3;
  
  // Phục hồi lại điện áp thực tế của Pin (Vì đã bị chia đôi qua 2 trở 100k)
  float batVoltage = adcVoltage * 2.0;

  // Tính phần trăm dung lượng (Giả sử dải hoạt động của pin Li-ion từ 3.2V đến 4.2V)
  int batPercent = 0;
  if (batVoltage >= 4.2) {
    batPercent = 100;
  } else if (batVoltage <= 3.2) {
    batPercent = 0;
  } else {
    // Ép kiểu phân số tuyến tính từ khoảng 3.2V - 4.2V sang 0% - 100%
    batPercent = (batVoltage - 3.2) / (4.2 - 3.2) * 100.0;
  }
  
  // Đảm bảo % không bị vượt quá giới hạn 0-100 do nhiễu số
  return constrain(batPercent, 0, 100);
}

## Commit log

2026-05-17 Upload PCB Project
    [PCB1.PcbDoc, PCB_Do_AN_1.PrjPcb, Schematic.SchDoc]
2026-05-17 Fix wire 30-35mils
2026-05-28 Update README with installation and deployment details
    Added installation and deployment instructions for the system, including hardware setup, database implementation, and ESP32 firmware loading.
2026-05-28 Upload Full Project Reworked
    [BOM.xlsx, PCB1.PcbDoc, PCB_Do_AN_1.PrjPcb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]

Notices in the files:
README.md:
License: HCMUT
